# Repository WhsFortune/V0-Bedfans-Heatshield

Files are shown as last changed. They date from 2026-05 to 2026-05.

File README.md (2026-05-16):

# V0 Bedfans Heatshield – Bedfan Mount with Heatshield for Voron V0 + Fysetc CNC Bed Carrier

[Deutsch](README.de.md) · **English**

> *Bedfans that leave your bed sensor alone.*

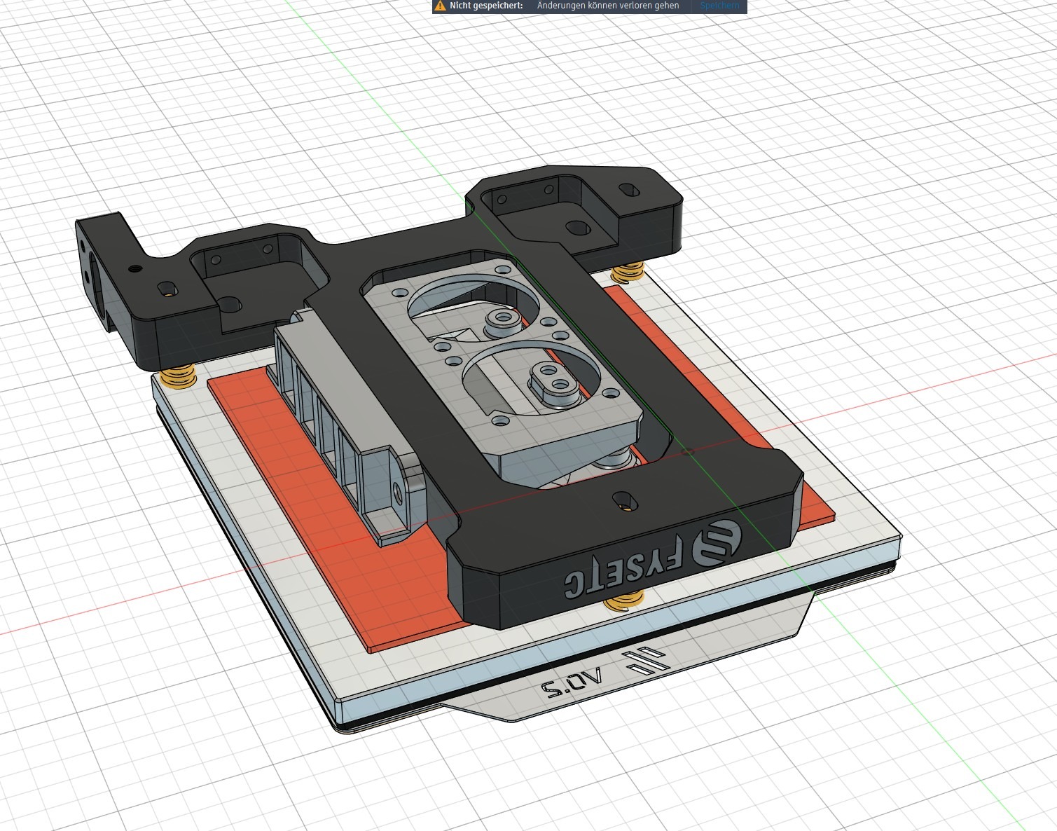
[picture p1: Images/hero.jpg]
Hero


Bedfan mount with a heatshield on top, for the **Voron V0 with Fysetc CNC bed carrier**. Three printed parts: a holder for two 3010 blowers, an opposing Wago holder, and a heatshield directly on the fans. The shield closes off the upward airflow and leaves ~3 mm of side gap to the heat mat, so the bedfan air exits sideways instead of blowing straight up against a centrally placed bed thermistor.

> *Inspired by the Voron V0 design (CC-BY-SA 4.0). All parts in this mod are original designs.*

---

## ⚠️ Compatibility

Only fits and only makes sense on:

- **Voron V0** with the **Fysetc CNC bed carrier**
- **Heat mat with a centrally placed thermistor** (e.g. Formbot V0 kit mat)

If your thermistor sits at the edge of the heat mat, you don't have the problem this mod solves.

---

## The problem

Standard bedfan mounts blow air straight up against the underside of the heat mat. A centrally placed thermistor sits right in that airflow and reports a temperature well below the real bed temperature. The printer heats at 100 % but the reading doesn't rise, and Klipper aborts with `heater not heating at expected rate`.

This mod deflects the airflow sideways with a heatshield directly on the fans. Thermistor stays out of the airflow, the bed reads correctly, and the fans still recirculate chamber air – heatsoak on the V0 noticeably speeds up.

---

## Print Settings

| Setting | Value |
|---|---|
| Material | **PC PBT GF** required – ABS/ASA is borderline this close to the heat mat. Creed PC PBT GF works well. |
| Layer height | 0.2 mm |
| Walls | 4 |
| Top/bottom layers | 4 |
| Infill | 40 % |
| Speed | **Print slowly** – PC PBT GF doesn't like high speeds |
| Supports | None needed – geometry is support-free |

---

## Bill of Materials

### Hardware

| Part | Qty |
|---|---|
| 3010 blower fan, 24 V (GDSTime recommended) | 2 |
| Wago 221-412 (2-pole) | 2 |

### Screws

| Type | Qty | Use |
|---|---|---|
| M3×20 BHCS (ISO 7380) | 2 | sandwich mount – one per side |
| M3×16 BHCS (ISO 7380) | 8 | heatshield stack – 4 per fan |

### Heat-Set Inserts

| Position | Qty |
|---|---|
| M3 in the fan holder (side) | 2 |
| M3 in the heatshield (top) | 8 |

---

## Assembly

1. Press the heat-set inserts: 2× M3 into the side of the fan holder, 8× M3 into the heatshield (four per fan position).
2. Place the 2× 3010 fans into the fan holder.
3. Lay the heatshield on top of the fans and drive **8× M3×16 BHCS from below** up through the fan holder, through the fans' corner holes, into the shield's inserts. This single stack holds the fans in the holder and the shield on top.
4. Place the fan holder centered in the heat-mat cutout of the Fysetc CNC bed carrier and the Wago holder on the opposite side.
5. Drive **2× M3×20 BHCS** from the outside of the Wago holder, through the carrier's side through-hole, into the M3 insert in the fan holder. One per side. This sandwich clamps the Wago holder, the bed carrier and the fan holder together – no tapping into aluminum.
6. Insert the 2× Wago 221-412 into the Wago holder.

After mounting, slowly home Z and verify the shield clears the heat mat. Intended gap is ~3 mm.

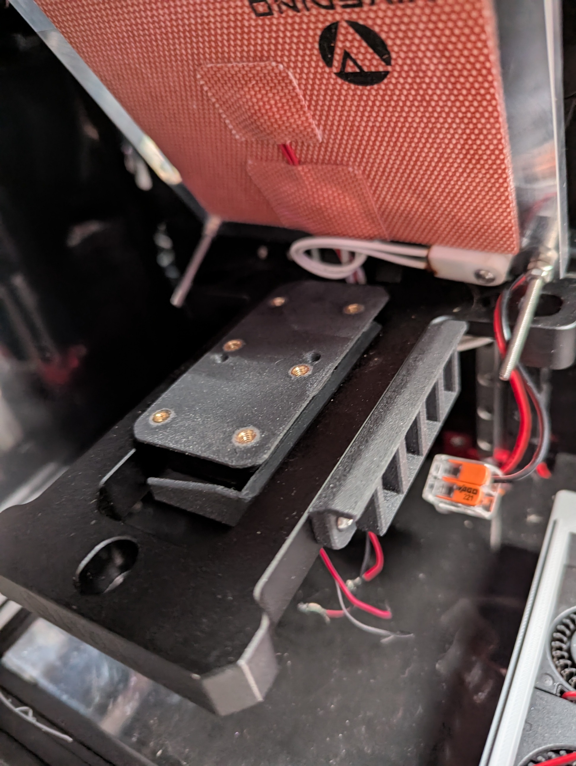
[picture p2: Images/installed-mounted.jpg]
Installed under the heat mat


---

## Wiring

The two 3010 fans connect to any free 24 V fan output on the printer via the Wagos.

---

## Files

- [`/3MF`](3MF/) – `V0-Bedfans-Heatshield.3mf` (all three parts in one file)
- [`/STEP`](STEP/) – editable in any CAD
- [`/CAD`](CAD/) – Fusion 360 native with full parametric tree

---

## License

[**CC-BY-SA 4.0**](LICENSE) – the Voron ecosystem standard. Forks and remixes welcome under the same license.

---

## Credits

- **Design:** Wh'sFortune
- **Inspired by:** [Voron V0](https://docs.vorondesign.com) (CC-BY-SA 4.0)
- **Companion mods:** [Aegis Chamber](https://github.com/WhsFortune/Projekt-Aegis) · [Filtra](https://github.com/WhsFortune/filtra)

Issues and feedback welcome on GitHub.

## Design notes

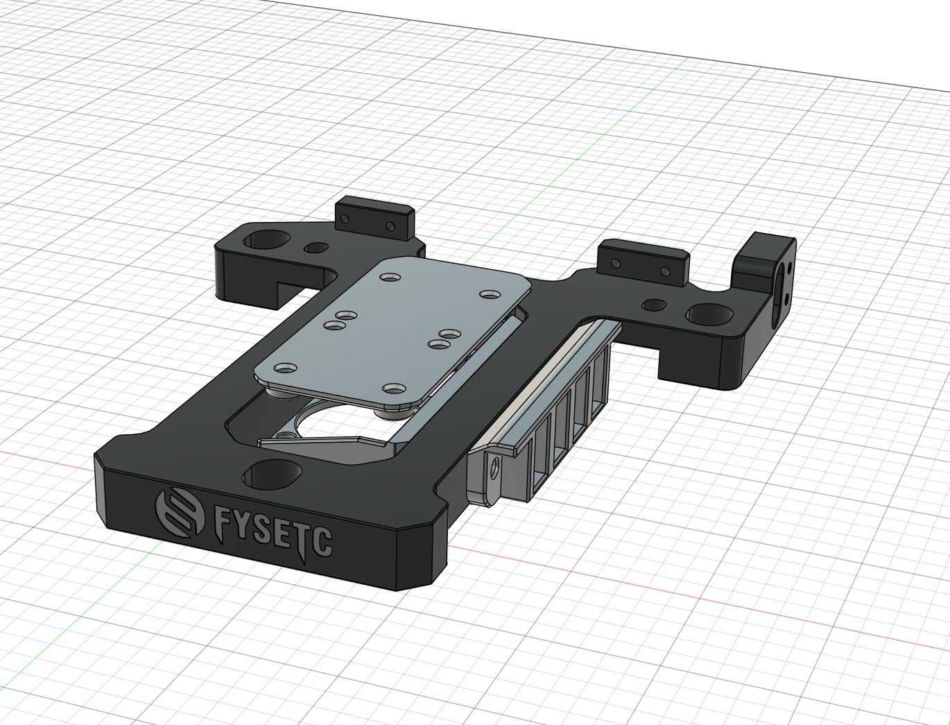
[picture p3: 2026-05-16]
Images/architecture.jpg

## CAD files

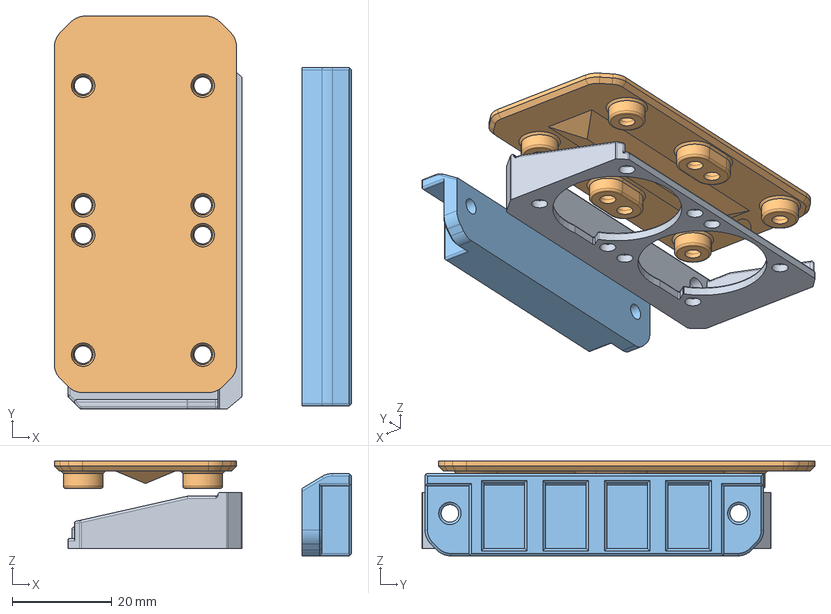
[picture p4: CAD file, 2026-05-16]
STEP/V0-Bedfans-Heatshield.step
59.7 x 78.9 x 19.0 mm

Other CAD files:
3MF/V0-Bedfans-Heatshield.3mf
CAD/V0-Bedfans-Heatshield.f3d

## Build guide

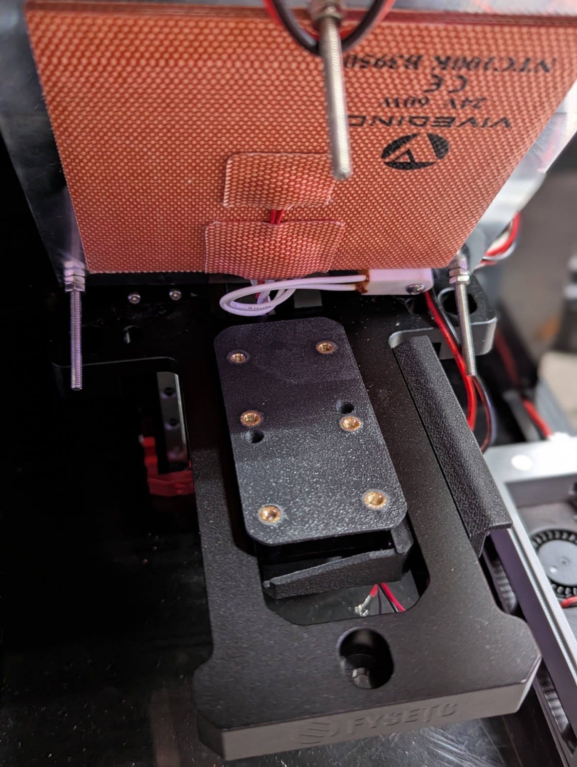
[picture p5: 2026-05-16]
Images/installed-perspective.jpg

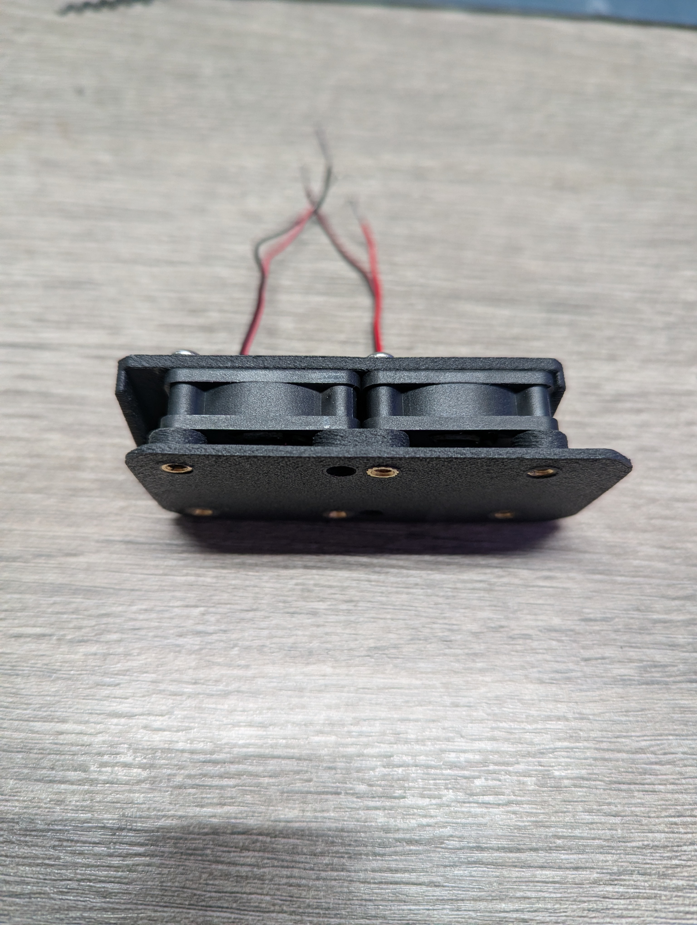
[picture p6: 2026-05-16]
Images/installed-side.jpg

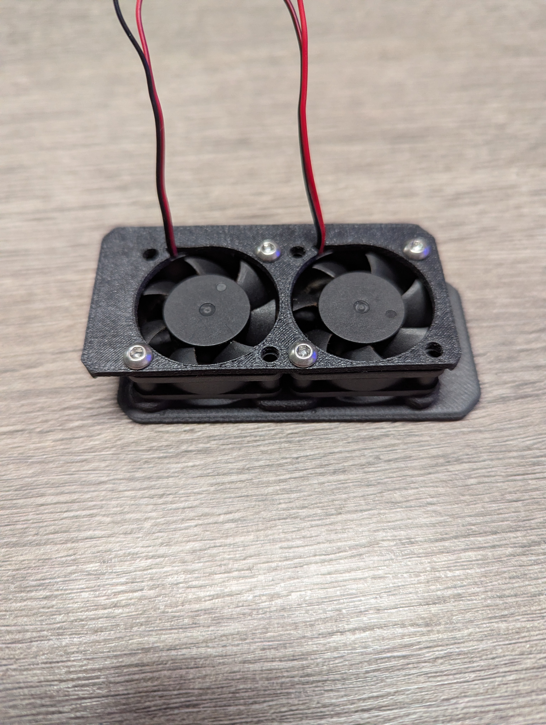
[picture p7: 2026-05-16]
Images/installed-front.jpg

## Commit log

2026-05-16 Tighten README – drop redundant sections, nozzle note, and spare-Wago wording
2026-05-16 BOM: 2 Wagos (one per fan), not 4
2026-05-16 Add two install photos, embed mounted view in README
